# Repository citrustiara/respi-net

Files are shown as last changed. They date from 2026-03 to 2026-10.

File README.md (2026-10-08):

# respi-net

Contactless breathing measurement with a 60 GHz Acconeer A121 radar, and the groundwork for a causal neural network
that recognises breathing phases (inhale, exhale, hold, noise) from the radar alone. Bachelor's thesis project
(praca inżynierska).

The project started with an HB100 Doppler module and IMUs (ESP32 + LSM6DS3). Those were a proof of concept; the
current work is A121-only.

## What is here

- **A121 signal chain** (`src/respi_net/chest_signal.py`): Sparse IQ → presence and chest range gates (Acconeer's
  breathing reference app) → unwrapped phase per gate → echo-weighted average → chest motion in mm (inhale up) →
  driver clock drift correction (0.17 %) → a 2 Hz low-pass as the only filter, so breath holds stay flat.
- **Desktop app** (`respi app`): live A121 view of the signal the network gets (range profile, chest motion and a
  small velocity strip, echo strength in the stats; ~0.2–0.3 s lag), CSV/SQLite recording, and a Recordings tab with curated demo recordings
  (`configs/demo_recordings.json`). Inhale/exhale shading and the older band-pass breathing/heart view are optional,
  under the *View* menu. Also supports HB100, the ESP32 IMU and the iPhone app.
- **iPhone app** (`ios/RespiPhoneIMU/`): streams CoreMotion accelerometer/gyro over BLE, saves every trial on the
  phone as well, remote start/stop from the desktop. Used as a timing helper for labels, never as a network input.
- **Breathing coach** (`respi coach`): the whole session drawn as the breath itself, countdown and next cue; JSON
  patterns in `configs/breathing_patterns/`. Guided recorders log cue times next to the radar and phone data.
- **Breathing-phase data**: classes after Szymański et al. (Sci Data 2025): 0 exhale, 1 hold after exhale,
  2 inhale, 3 hold after inhale, 4 noise, −1 ignored. Per-breath label correction, hand-annotation viewer, a loader
  for the Szymański respiratory-belt dataset (with its 0.2 s label offset corrected), augmented copies and a
  synthetic breathing generator passed through an A121 radar model.
- **Phase models** (`src/respi_net/phase_model.py`): causal TCN (~44k parameters, 25.5 s receptive field) and
  causal GRU (~38k), Viterbi / streaming decoding with phase-transition rules, and a deterministic baseline.
  Nothing has been trained yet; the target recordings are still being collected.
- **Earlier experiments**: lens comparison (hyperbolic, Fresnel zone plate, flat cover; aluminium foil gives no
  gain), sleep nights against a Garmin watch, heart rate from cardiac motion, HB100 vs A121.

## Quick start

```bash
uv sync
uv run respi app --sensor a121                      # live radar (serial port is auto-detected)
uv run respi app --sensor a121 --open data/raw/...csv   # open a recording, no hardware needed
uv run respi coach paced_12_hold                    # breathing coach
uv run respi --help                                 # all commands
uv run pytest -q
```

On macOS the Waveshare A121 board shows up as two ports, `/dev/cu.usbmodem…1` (interface A, the one to use) and
`…3`. Suggested app settings at 0.5–1.5 m: start 0.30 m, end 1.50 m, profile 3, HWAAS 32, 16 sweeps, 20 Hz,
live window 30 s.

Other useful commands:

```bash
uv run respi record-a121-test -p /dev/cu.usbmodemXXXX1 --label my-run    # record A121 until Ctrl+C
uv run respi record-a121-sleep -p /dev/cu.usbmodemXXXX1 --label night-1  # overnight recording + sleep analysis
uv run respi capture-iphone-imu --seconds 60        # iPhone IMU over BLE
uv run python tools/a121_iphone_guided_recording.py # A121 + iPhone with the coach
uv run python tools/annotate_phone_phases.py --session self_lying_3min_01 --run run_01_nn_self_3min --start 40 --length 60
uv run python tools/build_artificial_data.py        # augmented + synthetic training sets
uv run python tools/train_breath_phase_model.py --help
```

Full app and CLI reference: [`docs/APP_AND_CLI.md`](docs/APP_AND_CLI.md).

## Hardware

- Waveshare Acconeer A121 module (60 GHz pulsed coherent radar, USB), with a hyperbolic lens.
- iPhone with the RespiPhoneIMU app (labelling helper).
- Legacy: HB100 10.525 GHz module with a two-stage MCP6002 front end on an ESP32
  ([schematic](hardware/hb100_calibrated_schematic.svg)), LSM6DS3 IMU, AD8232 ECG for future heart-rate labels.

## Layout

- `src/respi_net/` – capture, signal processing, app, coach, datasets, models.
- `tools/` – guided recorders, analyses, dataset builders, training and figure scripts.
- `configs/` – breathing patterns, experiment configs, demo recordings list.
- `annotations/` – reviewed radar labels and small generated example datasets.
- `docs/thesis/` – thesis source (`praca_inzynierska.tex`) and figures; `docs/datasets/` – dataset notes.
- `ios/RespiPhoneIMU/` – iPhone app; `firmware/` – ESP32 firmware for the legacy sensors; `hardware/` – schematics.
- `data/` – recordings (large CSVs and third-party datasets are not committed).

## License

MIT, see [LICENSE](LICENSE). The Szymański et al. dataset is CC BY-NC-ND and is not redistributed here.

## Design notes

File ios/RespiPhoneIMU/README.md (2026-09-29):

# RespiPhoneIMU

Native SwiftUI iPhone companion app for streaming phone IMU data into RespiNet over Bluetooth Low Energy.

## Install on an iPhone

You need a Mac with Xcode for the final build/sign/install step. Apple does not ship the iOS SDK, device installer, or signing toolchain for Windows.

1. Copy or clone this repository on a Mac.
2. Install Xcode from the Mac App Store, then open Xcode once so it finishes installing components.
3. Connect the iPhone with USB, unlock it, and trust the Mac when prompted.
4. Open `ios/RespiPhoneIMU/RespiPhoneIMU.xcodeproj` in Xcode.
5. Select the `RespiPhoneIMU` target, then `Signing & Capabilities`.
6. Choose your Apple ID team. A free Apple ID is usually enough for direct development installs, though the app may expire and need reinstalling.
7. Select your physical iPhone as the run destination.
8. Press Run in Xcode.
9. If iOS asks for Developer Mode, enable it in Settings, restart the phone if prompted, then run again.

The simulator cannot provide real Bluetooth peripheral advertising or useful motion data, so use a physical iPhone. (In the simulator the app draws a made-up breath so its screens can be checked.)

## Using it for recordings

The app is meant to be strapped to the body, screen outwards, while the desktop recorder runs:

- **Before a trial** the main screen shows a checklist (Bluetooth, visible to the Mac, Mac connected, battery
  at least 30%, Low Power Mode off) and a **placement check**: a live line of the chest's tilt over the last
  30 s and its size in mg. With the strap tight, it rises and falls smoothly with each breath.
- **While streaming** a dark full-screen view shows the elapsed time, whether the Mac is connected, the live
  line and the measured rate, readable from a few metres. The screen dims (optional). Nothing on it reacts to
  a quick touch: stopping from the phone takes a 2-second hold, so a strap or shirt cannot stop a trial. The
  recorder normally starts and stops the stream itself.
- **If the Mac drops out** the phone vibrates and shows a red banner; it keeps saving.
- **Every trial is also saved on the phone** as `respi_imu_<date>_<time>.csv` in the same columns as the
  desktop files (`Time_ms,ax,ay,az,gx,gy,gz`, `Time_ms` in Unix ms from the phone's clock). They are listed
  under "Saved on this phone" with share (AirDrop) and delete buttons, and appear in the Files app under
  On My iPhone › Respi IMU. A trial the recorder rejects because Bluetooth lost samples is still complete here.

## Desktop capture

From this repository on the desktop:

```powershell
uv sync
uv run respi iphone-imu-devices
uv run respi capture-iphone-imu --seconds 60
```

Or open the desktop UI:

```powershell
uv run respi app --sensor iphone-imu
```

The saved CSV uses the same schema as the ESP32 IMU path:

```text
Time_ms,ax,ay,az,gx,gy,gz
```

Acceleration is in `g`; gyroscope values are in `deg/s`.

## BLE protocol

- Device name: `RespiPhoneIMU`
- Service UUID: `7B61B4E2-F5B4-4C90-8C7F-A7B2F1E8F4D0`
- Notify characteristic: `7B61B4E3-F5B4-4C90-8C7F-A7B2F1E8F4D0`
- Control characteristic: `7B61B4E4-F5B4-4C90-8C7F-A7B2F1E8F4D0`

The desktop writes ASCII `START` or `STOP` to the control characteristic. Notifications use little-endian binary payloads:

```text
uint8  version = 1
uint8  sample_count
uint16 sequence
repeat sample_count:
  uint32 time_ms_since_stream_start
  int16  ax_mg
  int16  ay_mg
  int16  az_mg
  int16  gx_centi_deg_per_s
  int16  gy_centi_deg_per_s
  int16  gz_centi_deg_per_s
```

The app adapts batch size to the central's `maximumUpdateValueLength`. With a 20-byte BLE payload it sends one sample per notification; with a larger MTU it sends multiple samples per notification.

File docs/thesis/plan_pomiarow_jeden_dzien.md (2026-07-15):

# Plan jednodniowych pomiarów przed spotkaniem z promotorem

Data przygotowania: 15.07.2026

## Cel dnia

W ciągu jednego dnia zebrać mały, ale metodologicznie czytelny zestaw danych,
który pozwoli odpowiedzieć na cztery pytania:

1. Czy sygnał oddechowy z aplikacji iPhone i z LSM6DS3 jest użyteczny w
   podstawowym wariancie leżenia na plecach?
2. Czy HB100 i A121 mogą pracować jednocześnie bez widocznego wzajemnego
   zakłócania?
3. Gdzie w praktyce kończy się użyteczny sygnał oddechowy HB100, gdy A121
   pracuje równolegle jako tor porównawczy?
4. Czy folia daje jakąkolwiek korzyść przy 2 m i czy wynik zależy od tego,
   czy radar pada na klatkę pod naturalnym kątem, czy niemal prostopadle?

Tego dnia nie powstaje szyna ani fantom z silnikiem. Część z siecią neuronową
zostaje do ustalenia z promotorem.

## Zasady wspólne

- Jedna osoba, ta sama odzież, możliwie to samo położenie czujników i stałe
  ustawienie fotela/łóżka w obrębie serii.
- Oddech zadany: metronom 12 odd./min, czyli 0,20 Hz. Wstrzymanie oddechu jest
  kontrolą negatywną, ale nie jest wzorcem amplitudy ani ruchu serca.
- Nagranie podstawowe trwa 60 s. Trzydzieści sekund daje przy 12 odd./min tylko
  sześć cykli, dlatego nadaje się do szybkiej kontroli lub bezdechu, ale jest
  słabe do stabilnej oceny widma.
- Schemat nagrania 60 s: 0–10 s uspokojenie, 10–45 s warunek właściwy,
  45–60 s wstrzymanie oddechu. Jeżeli wstrzymanie 15 s jest niekomfortowe,
  skrócić je; nie forsować go.
- Warunki A/B wykonywać parami i odwracać kolejność, np. AB, BA, AB. Nie robić
  całego bloku A, a potem całego bloku B.
- Nie używać `resp_confidence` ani `signal_quality` jako głównych wyników,
  ponieważ w dotychczasowych danych nasycały się. Zapisywać SNR widmowy,
  prominencję piku, trafienie zadanej częstości i stabilność między oknami.
- Przed startem utworzyć dziennik sesji. Minimalne kolumny:
  `run_id, czas, urządzenia, pozycja, dystans, folia, konfiguracja, kolejność,
  pliki, uwagi`.
- Po każdej serii od razu wpisać nazwy powstałych plików. Pliki HB100 nie mają
  etykiety warunku w nazwie, więc bez dziennika szybko tracą znaczenie.
- Dystans ustawiać tym samym dalmierzem MILESEEY D2 40 m. Radar pozostawić na
  statywie Manfrotto, a plamką lasera sprawdzać orientacyjne skierowanie osi na
  środek klatki piersiowej. W dzienniku zapisywać także wysokość i kąt albo
  przesunięcie poprzeczne stanowiska.

## Warunek konieczny: czas LSM6DS3

Obecny firmware LSM6DS3 wysyła sześć wartości bez czasu próbki, a komputer
nadaje czas przy odbiorze linii UART. Buforowanie może tworzyć zduplikowane lub
silnie skupione timestampy. Przed analizą ilościową trzeba:

1. dodać w firmware czas z `esp_timer_get_time()` albo monotonny licznik
   próbki,
2. przesyłać go jako pierwsze pole wiersza,
3. odczytać go w `src/respi_net/imu.py`, zamiast nadawać każdej linii
   `time.time()` na hoście,
4. w 60-sekundowym nagraniu nieruchomego czujnika sprawdzić medianę, histogram
   i percentyle odstępów czasu oraz liczbę odstępów równych zero.

Jeśli poprawka nie działa do 09:30, nie blokować całego dnia. Wykonać pełny
test iPhone, a LSM6DS3 potraktować wyłącznie jakościowo i jawnie opisać
ograniczenie czasowe.

## Harmonogram

| Czas | Zadanie | Wynik |
|---|---|---|
| 08:30–09:30 | timestamp LSM6DS3, test 60 s obu urządzeń nieruchomo | poprawna oś czasu lub jawny fallback |
| 09:30–10:15 | iPhone + LSM6DS3: leżenie na plecach | 4 wspólne nagrania po 60 s |
| 10:45–11:30 | test zakłóceń HB100–A121 | decyzja: razem czy osobno |
| 11:30–13:00 | przerwa i przygotowanie stanowiska dystansowego | geometria i lista dystansów |
| 13:00–14:30 | zasięg HB100; równolegle A121, jeśli test zakłóceń przeszedł | krzywa trafień/SNR względem dystansu |
| 14:30–15:45 | retest folii przy 2 m: geometria naturalna i prostopadła, tylko soczewka hiperboliczna | układ 2×2: kąt × folia |
| 15:45–16:30 | opcjonalny test odchylenia od osi A121, jeżeli wcześniejsze bloki skończą się poprawnie | sprawdzenie hipotezy o szerokości pola widzenia |
| 16:30–18:00 | kontrola plików, analiza, wykresy, kopia danych | materiał do pracy i dla promotora |

## 1. Test iPhone oraz LSM6DS3

Umieścić telefon i LSM6DS3 obok siebie na górnej części tułowia. Nie są w tym
eksperymencie referencją dla radaru; porównywane są dwa warianty samodzielnej
metody inercyjnej. Pozycja nie będzie identyczna co do milimetra, więc
porównanie amplitud między urządzeniami ma znaczenie drugorzędne.

Macierz minimalna:

| ID | Pozycja | Oddech | Powtórzenia | Czas |
|---|---|---:|---:|---:|
| IMU-L-N | na plecach | swobodny + końcowe wstrzymanie | 2 | 60 s |
| IMU-L-12 | na plecach | 12/min + końcowe wstrzymanie | 2 | 60 s |

Łącznie: 4 minuty czystego nagrania. Telefon i moduł położyć obok siebie na
górnej części klatki piersiowej i nie zmieniać ich orientacji między
powtórzeniami. Tego dnia nie rozszerzać macierzy o siedzenie, bok, brzuch,
stanie ani wiele lokalizacji. Wynik ma odpowiedzieć wyłącznie na pytanie, czy
oba tory dają użyteczny sygnał w najprostszym wariancie na plecach.

**TODO po teście podstawowym:** jeżeli oba urządzenia spełnią kryterium
użyteczności, wykonać osobną serię w pozycji siedzącej, a dopiero później
sprawdzić bok, różne ułożenia telefonu i odporność PCA na orientację. Bez tych
danych nie formułować wniosku o niezależności metody od postawy.

Komendy uruchamiane w dwóch terminalach:

```bash
uv run respi capture-imu --port <PORT_LSM6> --no-plot
uv run respi capture-iphone-imu --seconds 60 --no-plot
```

LSM6DS3 kończy się `Ctrl+C`; warto uruchomić go kilka sekund przed iPhone'em i
zatrzymać kilka sekund po nim.

Raportować osobno dla przyspieszenia i żyroskopu/PCA:

- rzeczywistą częstość próbkowania i histogram `Δt`,
- liczbę braków/powtórzeń czasu; dla BLE także luki sekwencji paczek (obecny
  odbiornik zachowuje ostatni numer, ale nie zlicza jeszcze przeskoków),
- częstotliwość dominującą i błąd względem 0,20 Hz w próbach z metronomem,
- SNR piku oddechowego i jego spadek podczas wstrzymania oddechu,
- stabilność wyniku między powtórzeniami w pozycji na plecach,
- udział wariancji wyjaśniony przez pierwszą składową PCA.

Robocze kryterium użyteczności: pik przy 0,20 Hz z błędem nie większym niż
0,02 Hz, co najmniej 6 dB nad medianą tła w paśmie oraz wyraźny spadek mocy
oddechowej podczas wstrzymania. Progi są kryteriami tego eksperymentu, a nie
normą kliniczną.

## 2. Czy HB100 i A121 mogą nagrywać równocześnie?

Ich częstotliwości podstawowe są daleko od siebie: HB100 pracuje przy
10,525 GHz, a A121 w paśmie 57–64 GHz. Bezpośrednie zakłócenie na
częstotliwości podstawowej jest więc mało prawdopodobne. Nie wolno jednak
przyjąć z góry, że zakłóceń nie ma: szósta harmoniczna HB100 wypada przy około
63,15 GHz, czyli wewnątrz pasma A121, a zakłócenie może też wejść przez wspólne
zasilanie USB lub przewody.

Ustawić oba radary tak jak w wykonanym pomiarze docelowym: obok siebie,
z~jednakowym nachyleniem, środkami apertur oddalonymi o 15 cm i~taką samą
odległością obu radarów od tułowia. Wykonać jeden krótki zapis każdego warunku:

| Warunek | A121 | HB100 | Scena |
|---|---|---|---|
| INT-A | nagrywa | wyłączony z zasilania | pusty, nieruchomy pokój |
| INT-B | nagrywa | włączony i nagrywa | pusty, nieruchomy pokój |
| INT-C | wyłączony z zasilania | nagrywa | pusty, nieruchomy pokój |

Każde nagranie: 30 s. Dla A121 porównać amplitudę tła i widmo szumu fazowego w
tej samej bramce; dla HB100 — RMS i widmo napięcia w pasmach 0,1–0,6 Hz oraz
0,6–5 Hz. Zmiana większa niż 3 dB, nowa stała linia widmowa albo wyraźna utrata
ramek jest sygnałem ostrzegawczym. Wtedy powtórzyć jedną parę z osobnymi
zasilaniami/hubami. Jeśli problem pozostaje, nie nagrywać radarów równocześnie.

Przykładowe terminale dla warunku wspólnego:

```bash
uv run respi capture-radar --port <PORT_HB100> --no-plot
uv run respi record-a121-test --port <PORT_A121> --seconds 30 \
  --label int-b-both --start-m 0.2 --end-m 1.5 \
  --profile 3 --hwaas 32 --sweeps-per-frame 8 --frame-rate-hz 20
```

## 3. Praktyczny limit HB100 z równoległym zapisem A121

### Wariant minimalny do wykonania teraz

Jeżeli celem jest przed spotkaniem pokazać przede wszystkim, **co da się
wycisnąć z HB100**, nie trzeba od razu wykonywać pełnej serii do 4 m. Najkrótszy
zestaw, który zachowuje sens metodyczny, wygląda następująco:

1. Zamocować HB100 i A121 obok siebie, z odległością środków apertur 15 cm,
   na wysokości mostka i z jednakowym nachyleniem. Dalmierzem ustawić tę samą
   odległość obu radarów od tułowia. A121 pozostawić z płaską pokrywą: jej
   szerokie pole widzenia jest bardziej porównywalne z HB100 niż pole soczewek
   skupiających, a sama osłona nie jest tu przedmiotem badania.
2. W pustej, nieruchomej scenie wykonać po 30 s: A121 przy wyłączonym HB100,
   oba radary włączone oraz HB100 przy wyłączonym A121. Jest to tylko szybki
   test przesiewowy zakłóceń. Gdy pojawi się nowa linia widmowa, wzrost tła
   ponad 3 dB albo utrata ramek, podejrzaną parę powtórzyć z osobnymi portami
   USB/zasilaniem; przy braku różnicy przejść od razu do pomiarów wspólnych.
3. Wykonać wspólne nagrania przy 30 cm (dwa powtórzenia), 60 cm (dwa
   powtórzenia) i 100 cm (dwa powtórzenia). Nie zmieniać wzmocnienia toru HB100
   między dystansami i zapisać, czy ADC nie ulega nasyceniu.
4. Jeżeli 100 cm spełnia kryterium użyteczności, wykonać jedno nagranie przy
   150 cm. Po sukcesie zwiększać dystans co 50 cm aż do pierwszego
   niepowodzenia. Powtórzyć tylko najdalszy dystans zaliczony oraz pierwszy
   niezaliczony. W powtórzeniu nieudanego warunku ponownie usiąść albo
   przesunąć krzesło radialnie o 1–2 cm, ponieważ jedokanałowy HB100 może
   znaleźć się w punkcie małej czułości fazowej. Dopiero niepowodzenie obu
   ustawień uznać za granicę; to wystarcza do podania jej praktycznego
   przedziału bez rozbudowanej macierzy.

Każde nagranie powinno trwać 90 s i powtarzać już użyty protokół A121:
10 s oddechu swobodnego, 7 cykli po 5 s (wdech 2 s, wydech 3 s), 15 s
wstrzymania po wydechu oraz 6 kolejnych cykli. Nie wykonywać na początku
dodatkowych ruchów synchronizacyjnych: prowadzony skrypt zapisuje dla obu
torów wspólny czas hosta, a pierwsze 10 s służy ustabilizowaniu pozycji.
Warunek zalicza się dla HB100, gdy pik przy 0,20 ± 0,02 Hz jest obecny w obu
częściach oddychania, ma co najmniej 6 dB nad tłem i wyraźnie zanika podczas
wstrzymania. A121 służy do sprawdzenia, czy w tym samym czasie rzeczywiście
zarejestrowano zadany przebieg; nie jest wzorcem klinicznym.

Taki wariant zajmuje około 10–15 minut czystego nagrywania plus zmiany
dystansu. Daje najlepszy przypadek, dwa powtórzenia przy odległościach
praktycznych oraz przedział granicy zasięgu. Dodatkowe dystanse i pełne
odwrócenie kolejności mają sens dopiero wtedy, gdy ta seria działa i ma zostać
użyta do mocniejszego wniosku ilościowego.

Prowadzony zapis całej procedury uruchamia osobny program:

```bash
uv run python tools/hb100_a121_guided_experiment.py
```

Program zapisuje HB100 i~A121 do osobnych plików CSV, dodaje wspólny czas hosta
i~plik z~fazami oddechu, prowadzi wszystkie trzy próby pustej sceny oraz dwie
próby przy 30, 60 i~100 cm. Klawisz `Esc` przerywa i~usuwa bieżący zapis. Po
100 cm można z~interfejsu dodać 150 cm i~kolejne dystanse co 50 cm; pierwsza
oznaczona porażka jest automatycznie powtarzana po zmianie pozycji o~1–2 cm.
Gdy podłączony jest tylko tor HB100, jego transmisję można najpierw sprawdzić
bez tworzenia właściwej sesji. Aktualny firmware używa 230400 baud i~stabilnej
częstości 250 Hz; skrypt sprawdza tę szybkość transmisji jako pierwszą, a tryb
zgodności pozostawia wyłącznie dla starszego obrazu 921600 baud:

```bash
uv run python tools/hb100_a121_guided_experiment.py --probe-hb100
```

### Wariant rozszerzony z pełną krzywą dystansu

Po pozytywnym teście zakłóceń nagrywać oba radary równocześnie. W tym
rozszerzonym wariancie A121 ma tylko soczewkę hiperboliczną; soczewki
zaprojektowanej dla około 60 GHz nie należy
zakładać na HB100 pracujący przy 10,525 GHz. Radary ustawić na wysokości
mostka, równolegle, bez zmiany statywów w całej serii.

Kolejność pierwszej serii, celowo niemonotoniczna:

`0,5 m → 2,0 m → 1,0 m → 3,0 m → 1,5 m → 4,0 m → 2,5 m`

Jeżeli pomieszczenie nie pozwala na 4 m, zakończyć na najdalszym mierzalnym
dystansie i podać ograniczenie pomieszczenia. Zrobić dwa powtórzenia każdego
dystansu, drugie w odwrotnej kolejności. Pomiędzy powtórzeniami wstać i usiąść
ponownie — pokaże to praktyczną wrażliwość HB100 na małą zmianę średniej
odległości bez budowania precyzyjnej szyny.

Stałe ustawienia A121: profil 3, HWAAS 32, 8 sweepów/ramkę, 20 Hz. Okno
odległościowe można przesuwać wraz z celem, ale powinno mieć stałą szerokość
około 1 m. Przykład dla 2 m:

```bash
uv run respi record-a121-test --port <PORT_A121> --seconds 60 \
  --label range-2m-r1 --start-m 1.5 --end-m 2.5 \
  --profile 3 --hwaas 32 --sweeps-per-frame 8 --frame-rate-hz 20
```

W drugim terminalu podczas tego samego warunku:

```bash
uv run respi capture-radar --port <PORT_HB100> --no-plot
```

Na początku i końcu wspólnego pomiaru wykonać trzy krótkie, wyraźne ruchy
tułowiem. Znaczniki HB100 są czasem od uruchomienia ESP32, a A121 używa czasu
hosta, więc te ruchy pozwalają później wyrównać przebiegi. Do porównania samej
częstości oddechu dokładna synchronizacja nie jest konieczna.

Za trafienie uznać pik `0,20 ± 0,02 Hz`, obecny w kolejnych oknach i z SNR co
najmniej 6 dB. Dla HB100 dodatkowo policzyć stosunek energii 0,20 Hz do drugiej
harmonicznej 0,40 Hz. Dominacja 0,40 Hz jest praktycznym przykładem ograniczenia
jednokanałowego CW, a nie poprawną detekcją 24 odd./min.

Zasięg roboczy raportować jako najdalszy dystans spełniający kryterium w obu
powtórzeniach. Najbliższy dystans niespełniający kryterium powtórzyć trzy razy
po 60 s. Jeśli A121 zawiedzie, wykonać tylko jedną serię ratunkową z profilem 4
i HWAAS 128; oznaczyć ją jako konfigurację strojoną i nie mieszać z serią
podstawową.

## 4. Retest folii przy 2 m: geometria naturalna i prostopadła

**Status: wykonano 15 lipca 2026.** Zarejestrowano komplet 12 prób w sesji
`guided_foil2m_2026-07-15_16-26-15`. Analizę odtwarza
`tools/analyze_a121_foil_2m.py`; wyniki i wnioski wpisano do sekcji
„Retest folii i kąta padania na dystansie 2 m” pracy.

Celem retestu jest rozdzielenie dwóch możliwych wyjaśnień dotychczasowego
wyniku: folia rzeczywiście nie poprawia pomiaru albo przy naturalnym kącie
odbicie zwierciadlane jest kierowane poza radar.

Ustawienia wspólne:

- wyłącznie A121 z soczewką hiperboliczną;
- dystans 2,0 m, profil 3, HWAAS 32, 8 sweepów/ramkę, 20 Hz, zakres 1,5–2,5 m;
- pozycja siedząca na tym samym krześle i ta sama warstwa odzieży;
- łata 5 × 5 cm; jej górna krawędź 5 cm poniżej poziomej linii łączącej
  brodawki sutkowe;
- każde nagranie 90 s według identycznych komunikatów programu:
  0–10 s oddech swobodny, 10–45 s siedem cykli 12/min (wdech 2 s, wydech
  3 s), 45–60 s wstrzymanie po wydechu i 60–90 s sześć kolejnych cykli
  12/min. Wstrzymania nie forsować; przy dyskomforcie przerwać i odrzucić
  próbę.

Badane są dwa ustawienia geometryczne:

- **N — naturalne:** niewymuszona pozycja siedząca, radar równoległy do
  podłoża i sprawdzony poziomnicą pęcherzykową. Oś radaru tworzy około 30° z
  normalną do klatki, tak jak w pierwszym eksperymencie.
- **P — prawie prostopadłe:** wiązka pada możliwie pod kątem 90° do
  powierzchni klatki, czyli 0° względem jej normalnej. Najlepiej uzyskać to
  przez zmianę pochylenia i wysokości głowicy statywu, bez wymuszania innej
  pozycji ciała. Oś nadal ma trafiać w środek łaty, a odległość pozostać 2,0 m.

Dla każdego ustawienia wykonywane są nagrania z folią i bez folii:

| Kod | Geometria | Folia |
|---|---|---|
| N0 | naturalna, około 30° od normalnej | brak |
| NF | naturalna, około 30° od normalnej | jest |
| P0 | prawie 90° do powierzchni / 0° od normalnej | brak |
| PF | prawie 90° do powierzchni / 0° od normalnej | jest |

### Weryfikacja ustawienia prostopadłego laserem

1. Dalmierz ustawić sztywno przy radarze tak, aby jego oś lasera była
   równoległa do osi A121; sposób mocowania sfotografować.
2. Z założoną i możliwie wygładzoną folią skierować laser w środek łaty.
3. Regulować pochylenie głowicy statywu do chwili, gdy odbity punkt lasera
   wraca możliwie blisko miejsca emisji. Powrót obserwować na małej matowej,
   białej kartce umieszczonej przy aperturze dalmierza, a nie patrząc wzdłuż
   wiązki ani w jej zwierciadlane odbicie.
4. Zablokować głowicę i zaznaczyć pozycję krzesła. Ustawienie opisać jako
   „prawie prostopadłe”, ponieważ pofałdowana folia i krzywizna klatki nie
   tworzą idealnej płaszczyzny.
5. Zaznaczyć dwa powtarzalne położenia głowicy statywu: N (naturalne) i P
   (prawie prostopadłe). W bloku z folią przełączać wyłącznie położenie
   statywu, nie odklejając łaty.
6. Po szóstej próbie, zakończonej w warunku PF, zdjąć folię jeden raz bez
   zmiany statywu ani krzesła i od razu wykonać P0. W całym drugim bloku
   odtwarzać N i P z oznaczeń, bez ponownego przyklejania folii.

Każdy z czterech warunków wykonać trzy razy. Folia jest przyklejana tylko raz
przed próbą 1 i zdejmowana tylko raz między próbą 6 a 7. Kolejność geometrii
jest odwrócona w drugim bloku:

- blok z folią: `NF → PF → PF → NF → NF → PF`,
- blok bez folii: `P0 → N0 → N0 → P0 → P0 → N0`.

Taki układ eliminuje odklejanie i ponowne przyklejanie łaty, ale nie rozdziela
w pełni efektu folii od dryfu w czasie: wszystkie pomiary z folią są wykonane
wcześniej. Wynik należy więc opisać jako pilotażowy, a spójny spadek lub wzrost
wszystkich metryk w drugim bloku traktować również jako możliwy efekt sesji.

Daje to 12 nagrań i po trzy realizacje każdego warunku. Przykładowa komenda:

```bash
uv run python tools/a121_foil_2m_experiment.py
```

Runner sam realizuje powyższą kolejność i wyraźnie wskazuje moment jednorazowego
zdjęcia folii. Pokazuje duże komunikaty `WDECH`,
`WYDECH` i `WSTRZYMAJ ODDECH`, odlicza czas do zmiany oraz zapisuje rozwiniętą
oś poleceń w manifeście sesji. `Esc` lub czerwony przycisk przerywa aktywną
próbę i usuwa jej plik; ten sam warunek pozostaje wtedy gotowy do ponowienia.

Najpierw policzyć efekt folii osobno dla obu geometrii:

- `ΔN = NF − N0` — efekt folii w pozycji naturalnej,
- `ΔP = PF − P0` — efekt folii przy padaniu prawie prostopadłym,
- `ΔP − ΔN` — informacja, czy korzyść z folii zależy od kąta.

Porównać amplitudę w bramce klatki, SNR, prominencję piku, stabilność
odległości i trafienie 0,20 ± 0,02 Hz. Jeśli poprawa pojawi się tylko w PF,
wynik będzie wspierał hipotezę o kierowaniu odbicia poza radar w naturalnej
geometrii. Brak poprawy w NF i PF będzie wskazywał, że łata nie daje praktycznej
korzyści również przy korzystnym ustawieniu. Przy trzech powtórzeniach wynik
pozostaje pilotażowy: pokazać wszystkie punkty i mediany różnic, bez mocnego
wniosku opartego wyłącznie na p-value.

## 5. Opcjonalny test odchylenia od osi A121

Ten test ma większą wartość dla głównego, radarowego tematu pracy niż dalsze
rozszerzanie macierzy IMU. Sprawdza hipotezę, że soczewka skupiająca daje
większy zysk przy poprawnym wycelowaniu, ale płaska pokrywa jest bardziej
odporna na przesunięcie śpiącej osoby poza oś radaru.

- Dystans nominalny: 1,0 m. Przy tym dystansie dotychczasowy SNR jest duży,
  więc spadku jakości nie powinien powodować sam brak mocy.
- Warianty: soczewka hiperboliczna i płaska pokrywa; FZP pominąć.
- Położenie środka klatki poza osią głównej wiązki: 0°, 15° i 30°.
- Dwa powtórzenia każdego warunku, po 60 s, oddech 12/min.
- Kolejność przeplatać między soczewkami i kątami.
- Metryki: amplituda w bramce klatki, SNR, prominencja piku, stabilność
  śledzonej odległości i odsetek okien trafiających 0,20 ± 0,02 Hz.

Jeżeli statyw nie ma wiarygodnej podziałki kąta, można pozostawić radar
nieruchomo i przesunąć badanego poprzecznie względem osi. Dla odległości 1 m
przesunięcia odpowiadające w przybliżeniu 15° i 30° wynoszą odpowiednio
0,27 m i 0,58 m (`x = R·tan(θ)`). Bez wykonania tego testu w pracy należy
pozostawić sformułowanie „prawdopodobne wyjaśnienie geometryczne”, a nie
„przyczyną była niewłaściwa pozycja radaru”.

Nie należy mylić tego testu z kątem padania na powierzchnię klatki. Retest
z sekcji 4 porównuje 30° i 0° względem normalnej, aby zbadać kierunkowość
odbicia od folii. Test odchylenia od osi pozostawia orientację tułowia stałą,
ale przesuwa jego środek poza główną oś radaru, aby zbadać pole widzenia
soczewek.

## Wykresy do zrobienia tego samego dnia

1. iPhone i LSM6DS3: sygnał + PSD dla leżenia na plecach oraz histogram `Δt`.
2. Trafienie 0,20 Hz i SNR względem dystansu dla A121 i HB100.
3. HB100: energia składowej podstawowej 0,20 Hz oraz harmonicznej 0,40 Hz w
   każdym powtórzeniu.
4. Folia 2 m: delty `NF−N0` i `PF−P0` dla amplitudy i SNR oraz porównanie
   efektu folii między geometrią naturalną i prostopadłą.
5. Jeżeli wykonano test kąta: SNR i odsetek trafionych okien względem kąta,
   osobne krzywe dla soczewki hiperbolicznej i płaskiej pokrywy.

## Minimalny rezultat dla promotora

Nawet gdy część prób zawiedzie, dzień jest udany, jeżeli powstaną:

- jawny wniosek o jakości timestampów i BLE,
- tabela „iPhone/LSM6DS3 × oddech swobodny/narzucony” dla pozycji na plecach,
  z kryteriami użyteczności,
- test wykluczający albo ujawniający zakłócenia HB100–A121,
- empiryczna granica odległości z warunkiem trafienia, a nie oceną „na oko”,
- uczciwy pilotaż folii przy 2 m wykonany w dwóch kolejnych blokach (najpierw
  wszystkie próby z folią, następnie wszystkie bez niej), osobno dla
  naturalnego kąta i padania prawie prostopadłego.

Test kąta jest dodatkiem o dużej wartości interpretacyjnej, ale nie jest
warunkiem minimalnego wyniku dnia.

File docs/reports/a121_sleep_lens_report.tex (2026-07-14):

\documentclass[11pt,a4paper]{article}
\usepackage[utf8]{inputenc}
\usepackage[T1]{fontenc}
\usepackage[margin=2.4cm]{geometry}
\usepackage{graphicx}
\usepackage{booktabs}
\usepackage{array}
\usepackage{longtable}
\usepackage{float}
\usepackage{subcaption}
\usepackage{hyperref}
\usepackage{amsmath}
\usepackage{caption}
\usepackage{siunitx}
\graphicspath{{../../data/plots/}}

\title{A121 Sleep Radar Lens Experiments\\\large Overnight comparison of plano-convex, FZP, and flat-cover configurations with Garmin reference data}
\author{}
\date{June 2026}

\begin{document}
\maketitle

\begin{abstract}
This report summarizes three overnight A121 radar sleep recordings and two short follow-up bench tests performed while changing the front-end optical/mechanical configuration: a plano-convex lens (night 1\_1), a Fresnel zone plate (FZP) lens (night 2), and a flat cover that behaved approximately like a no-lens condition (night 3). Garmin heart-rate (HR), respiration-rate (RR), and sleep-stage overlays were used as the main external reference. A key result of the analysis is that raw radar \texttt{peak\_amplitude} cannot be interpreted as chest-signal strength in this setup, because the radar was placed near the bed edge and the dominant reflector was often closer than the tracked subject distance. The most meaningful comparison therefore comes from Garmin agreement and from the plausibility/stability of the radar-derived sleep metrics. Night 3, despite having no focusing lens, produced the closest HR agreement to Garmin, while nights 1\_1 and 2 showed larger HR bias and heuristic REM$\rightarrow$deep transitions not present in Garmin. The short \SI{2}{m} retest showed only a small amplitude increase with the plano-convex lens compared with no lens, but the lens produced more plausible HR estimates.
\end{abstract}

\section{Background and framing}
Acconeer's lens design documentation notes that dielectric lenses are mainly used to shape the radiation pattern, increase gain, narrow the beamwidth, and in some cases suppress unwanted reflections. The same documentation presents both a plano-convex example lens and an FZP example lens for A121-class hardware, and explicitly notes that focal distance may require tuning because the optimum can shift due to the radome, housing, material tolerances, and nearby mechanics. This point is directly relevant here because the experiments were performed in a bedroom geometry with the radar mounted near the bed edge rather than in a controlled free-space test fixture.

\paragraph{Interpretation rule used throughout this report.}
\begin{quote}
\textbf{Raw \texttt{peak\_amplitude} is treated only as a dominant-return engineering metric, not as a direct proxy for chest reflection strength or physiological signal quality.} The reason is that the strongest radar return could originate from the bed edge, mattress, bedding, or another static reflector rather than the subject.
\end{quote}

This framing is important because the raw peak amplitudes differed by more than an order of magnitude between nights, yet the strongest returns were often not spatially aligned with the tracked target distance.

\section{Experimental conditions}
Table~\ref{tab:nights} summarizes the three overnight recordings used in the comparison. Night 3 was interrupted, so it contains only about three hours of usable data. The Garmin overlay plots and the radar sleep-score JSON sidecars were generated for all three nights.

\begin{table}[H]
\centering
\caption{Overnight recordings and hardware condition.}
\label{tab:nights}
\begin{tabular}{@{}lllll@{}}
\toprule
Night & Date & Front-end condition & Recording length & Note \\
\midrule
1\_1 & 2026-06-08 & Plano-convex lens & 6.95 h & Full night \\
2 & 2026-06-09 & FZP lens & 6.48 h & Full night \\
3 & 2026-06-10 & Flat cover / effectively no lens & 3.56 h & Interrupted recording \\
\bottomrule
\end{tabular}
\end{table}

The A121 lens documentation is useful for interpreting these tests:
\begin{itemize}
    \item dielectric lenses can increase gain and narrow the beam,
    \item the plano-convex and FZP lenses are both valid A121-compatible example designs,
    \item FZP lenses are mechanically thinner and their thickness is less coupled to diameter,
    \item the effective focal point can shift because of radome/housing effects and nearby mechanics.
\end{itemize}
These points make aiming and lens-to-radar spacing critical, especially in a bed-edge mounting geometry.

\section{Analysis method}
The overnight data were processed with the repository's A121 sleep-analysis pipeline. For each night the following outputs were generated and used here:
\begin{itemize}
    \item gated radar HR/RR trends,
    \item radar sleep-phase heuristic and radar sleep score,
    \item Garmin HR/RR overlays,
    \item radar sleep-parameter JSON sidecars,
    \item diagnostic comparison plots.
\end{itemize}

The following metrics were extracted:
\begin{enumerate}
    \item radar sleep score, total sleep time, efficiency, and estimated resting HR,
    \item mean and median HR/RR compared against Garmin,
    \item sleep-stage duration sums (where available from the analysis session),
    \item direct REM$\rightarrow$deep transition counts,
    \item dominant-return peak amplitude and its spatial alignment to the tracked target distance,
    \item short timed lens vs. no-lens retest diagnostics at roughly \SI{2}{m}.
\end{enumerate}

Estimated resting HR was added to the automatic radar sleep JSON files and defined as the \emph{10th percentile of quiet, non-awake radar HR windows inside the inferred sleep interval}. This makes it more robust than taking a raw minimum while still approximating the lower resting envelope overnight.

\section{Primary overnight results}

\subsection{Radar-only sleep summary}
Table~\ref{tab:radarsleep} summarizes the radar-inferred overnight sleep metrics.

\begin{table}[H]
\centering
\caption{Radar sleep summary from the generated JSON sidecars.}
\label{tab:radarsleep}
\resizebox{\textwidth}{!}{%
\begin{tabular}{@{}lrrrrr@{}}
\toprule
Night & Score & Total sleep [min] & Efficiency [\%] & Estimated resting HR [bpm] & Quality \\
\midrule
1\_1 & 74 & 364.5 & 93.8 & 52.7 & Fair \\
2 & 71 & 342.5 & 95.0 & 51.9 & Fair \\
3 & 49 & 154.0 & 85.8 & 50.8 & Poor \\
\bottomrule
\end{tabular}%
}
\end{table}

Night 3 scored substantially worse mainly because the recording was interrupted and therefore short; the score was capped by duration. The estimated resting HR remained internally consistent across nights, staying in the low-50 bpm range.

\subsection{Heart-rate comparison against Garmin}
Garmin agreement is the most important outcome because it is much less sensitive to the bed-edge reflector issue than raw radar amplitude. Table~\ref{tab:hr} uses the sleep-only comparison windows discussed during the analysis session.

\begin{table}[H]
\centering
\caption{Sleep-only heart-rate comparison between radar and Garmin.}
\label{tab:hr}
\resizebox{\textwidth}{!}{%
\begin{tabular}{@{}lrrrrrr@{}}
\toprule
Night & Radar mean & Radar median & Garmin mean & Garmin median & Mean bias & Median bias \\
 & [bpm] & [bpm] & [bpm] & [bpm] & radar$-$Garmin & radar$-$Garmin \\
\midrule
1\_1 & 55.5 & 55.2 & 57.4 & 57.0 & -1.9 & -1.8 \\
2 & 55.1 & 54.6 & 58.3 & 57.0 & -3.3 & -2.4 \\
3 & 53.8 & 53.3 & 53.6 & 52.0 & +0.1 & +1.3 \\
\bottomrule
\end{tabular}%
}
\end{table}

The HR comparison shows the clearest practical result of the experiment: the flat-cover night (night 3) matched Garmin best, while the two lensed nights under-read HR on average. This does \emph{not} prove that the flat cover is universally better than a lens; it does show that the tested lens geometries did not automatically translate into better overnight physiological agreement in this mounting arrangement.

\subsection{Respiration-rate comparison against Garmin}
RR agreement was generally closer than HR agreement. Table~\ref{tab:rr} summarizes the values used during the analysis.

\begin{table}[H]
\centering
\caption{Sleep-only respiration-rate comparison between radar and Garmin.}
\label{tab:rr}
\resizebox{\textwidth}{!}{%
\begin{tabular}{@{}lrrrrrr@{}}
\toprule
Night & Radar mean & Radar median & Garmin mean & Garmin median & Mean bias & Median bias \\
 & [brpm] & [brpm] & [brpm] & [brpm] & radar$-$Garmin & radar$-$Garmin \\
\midrule
1\_1 & 13.6 & 14.2 & 14.0 & 14.4 & -0.4 & -0.2 \\
2 & 14.6 & 14.9 & 14.2 & 14.4 & +0.4 & +0.5 \\
3 & 14.3 & 14.3 & 14.0 & 14.1 & +0.3 & +0.2 \\
\bottomrule
\end{tabular}%
}
\end{table}

RR stayed within about half a breath per minute of Garmin on average for all three nights. This is a stronger and more stable result than the raw peak-amplitude comparison.

\subsection{Sleep-stage duration comparison}
For nights 1\_1 and 2, the analysis session retained quantitative radar-vs-Garmin sleep-stage duration sums extracted from the Garmin FIT stage data. These values are shown in Table~\ref{tab:stages}. Night 3 was interrupted and is therefore discussed primarily through the overlay plot and radar-only sleep summary.

\begin{table}[H]
\centering
\caption{Sleep-stage duration sums for nights 1\_1 and 2. Positive difference means radar assigned more time to that stage than Garmin.}
\label{tab:stages}
\resizebox{\textwidth}{!}{%
\begin{tabular}{@{}llrrrr@{}}
\toprule
Night & Source & Awake [min] & Light [min] & Deep [min] & REM [min] \\
\midrule
1\_1 & Radar & 24.0 & 212.5 & 78.5 & 73.5 \\
1\_1 & Garmin & 40.0 & 222.0 & 57.0 & 47.0 \\
1\_1 & Difference & -16.0 & -9.5 & +21.5 & +26.5 \\
\midrule
2 & Radar & 18.0 & 191.0 & 58.0 & 93.5 \\
2 & Garmin & 5.0 & 211.0 & 18.0 & 117.0 \\
2 & Difference & +13.0 & -20.0 & +40.0 & -23.5 \\
\bottomrule
\end{tabular}%
}
\end{table}

Two additional stage-related observations were important:
\begin{itemize}
    \item Nights 1\_1 and 2 contained direct radar REM$\rightarrow$deep transitions (two such transitions on each night), while Garmin showed zero direct REM$\rightarrow$deep transitions in those same nights.
    \item This suggests that at least part of the radar stage disagreement came from the heuristic classifier rather than from the raw HR/RR tracking alone.
\end{itemize}

\section{Why peak amplitude must be interpreted carefully}
The raw peak-amplitude plot across nights is striking: the median dominant return rises from roughly \num{1.7e3} in night 1\_1 to \num{1.75e4} in night 2 and \num{2.36e4} in night 3. However, Table~\ref{tab:peak} shows why this cannot be interpreted as ``better chest signal''.

\begin{table}[H]
\centering
\caption{Dominant-return amplitude and target-alignment diagnostics from the gated sleep-vitals CSV files.}
\label{tab:peak}
\resizebox{\textwidth}{!}{%
\begin{tabular}{@{}lrrrrrr@{}}
\toprule
Night & Peak amp median & Peak amp mean & Median target dist & Median peak dist & Median $|\Delta d|$ & Fraction with $|\Delta d|\leq$0.10 m \\
 & [a.u.] & [a.u.] & [m] & [m] & [m] & [-] \\
\midrule
1\_1 & 1665.2 & 3079.7 & 0.37 & 0.15 & 0.16 & 0.316 \\
2 & 17515.5 & 17659.7 & 0.44 & 0.12 & 0.32 & 0.012 \\
3 & 23574.3 & 23240.3 & 0.22 & 0.10 & 0.12 & 0.384 \\
\bottomrule
\end{tabular}%
}
\end{table}

The median dominant-return distance was much closer than the tracked target distance on all nights, especially on night 2. The FZP night is the clearest example: despite a median peak amplitude above \num{1.7e4}, only about \SI{1.2}{\percent} of windows had the dominant peak within \SI{10}{cm} of the target. This makes it highly likely that the large peak came from the bed edge or another nearby reflector rather than from the subject.

This is the reason for the specific presentation used in this report:
\begin{enumerate}
    \item Garmin HR/RR agreement is treated as the \textbf{primary outcome},
    \item sleep-stage agreement is treated as the \textbf{secondary outcome},
    \item raw peak amplitude is treated only as a \textbf{contextual engineering variable}. 
\end{enumerate}

\section{Short follow-up retest at approximately \SI{2}{m}}
A short retest was performed after the overnight analysis to check whether the plano-convex lens behaved more sensibly at a longer distance, where aiming is easier. One \SI{90}{s} sample was recorded with the lens and one without the lens.

\begin{table}[H]
\centering
\caption{Short \SI{2}{m} timed retest: lens vs. no lens.}
\label{tab:2mtest}
\resizebox{\textwidth}{!}{%
\begin{tabular}{@{}lrrrrrr@{}}
\toprule
Condition & Target dist [m] & Avg peak amp & Batch HR & Batch HR conf. & Weighted HR & Weighted HR conf. \\
\midrule
Plano-convex lens & 1.862 & 556 & 62.5 & 12.5 & 54.5 & 8.6 \\
No lens & 1.682 & 491 & 102.1 & 6.7 & 83.2 & 5.8 \\
\bottomrule
\end{tabular}%
}
\end{table}

The lens increased average peak amplitude only modestly (about \SI{13}{\percent}), so this was not a dramatic gain result. However, the lens case produced a much more plausible HR estimate than the no-lens case. This again supports the main argument of the report: \emph{amplitude alone is not the right decision metric}. A configuration can have only a small amplitude advantage yet still produce more believable physiology.

\section{Plots}
The generated plots are included below because the time-domain behavior is at least as informative as the summary tables.

\begin{figure}[p]
    \centering
    
    \caption{Night 1\_1: plano-convex lens. Radar HR/RR and heuristic sleep phases overlaid with Garmin reference data.}
\end{figure}

\begin{figure}[p]
    \centering
    
    \caption{Night 2: FZP lens. This night had high dominant-return amplitude, but the strongest reflector was usually not at the tracked target distance.}
\end{figure}

\begin{figure}[p]
    \centering
    
    \caption{Night 3: flat cover / effectively no lens. The recording was interrupted, but the HR agreement with Garmin was the best of the three nights.}
\end{figure}

\begin{figure}[p]
    \centering
    
    \caption{Dominant-return peak amplitude across the three overnight recordings. This figure is useful as engineering context, but it should not be read as a direct measure of chest-signal strength.}
\end{figure}

\begin{figure}[p]
    \centering
    \begin{subfigure}[t]{0.49\textwidth}
        \centering
        
        \caption{Plano-convex lens at about \SI{2}{m}.}
    \end{subfigure}
    \hfill
    \begin{subfigure}[t]{0.49\textwidth}
        \centering
        
        \caption{No lens at about \SI{2}{m}.}
    \end{subfigure}
    \caption{Short timed retest used to probe whether the plano-convex lens behaves better when moved farther away to make aiming easier.}
\end{figure}

\section{Discussion}
\subsection{What the Garmin comparison says}
The overnight Garmin comparison is the strongest result available from the current data. RR agreement remained fairly close to Garmin on all three nights, typically within about \SI{0.5}{brpm}. HR was more discriminative: the flat-cover night agreed best with Garmin, while the lensed nights under-read HR by roughly \SIrange{2}{3}{bpm} on average.

\subsection{What the peak amplitudes do \emph{not} say}
The very large raw amplitudes on nights 2 and 3 are not evidence that those nights had stronger physiological returns from the chest. In fact, the target-alignment table suggests the opposite interpretation: the strongest reflector was often spatially separated from the tracked target by \SIrange{0.12}{0.32}{m}. This is fully consistent with a bed-edge setup where the mattress, bed frame, or nearby bedding can dominate the return.

\subsection{What can still be said about the lenses}
The data do not justify a simple ``higher amplitude = better lens'' conclusion. Instead, the results suggest the following:
\begin{itemize}
    \item the plano-convex lens in night 1\_1 may have been mis-aimed and/or used at a geometry that did not place the subject well within the main lobe,
    \item the FZP night produced a very strong dominant reflector but poor target alignment, so the large peak was likely not the subject,
    \item the flat-cover night produced the best HR agreement, which means the simpler configuration was the most reliable in this specific mounting arrangement,
    \item the short \SI{2}{m} retest suggests that moving the lens farther away may improve practical aiming, but the current retest still showed only a small raw amplitude gain.
\end{itemize}

\subsection{REM-to-deep transitions}
The direct REM$\rightarrow$deep transitions seen in the radar heuristic but not in Garmin indicate that the stage classifier should still be treated as exploratory. The HR/RR overlays appear more trustworthy than the exact radar stage labels at this point.

\subsection{Limitations}
This comparison has several limitations:
\begin{itemize}
    \item only one main overnight recording per lens condition,
    \item night 3 was interrupted,
    \item the radar geometry was not fixed in a controlled mechanical jig,
    \item Garmin is a practical consumer reference, not polysomnography,
    \item the dominant-return amplitude was confounded by bed-edge reflections.
\end{itemize}

\section{Overall findings}
The main conclusions of the current experiment are as follows:
\begin{enumerate}
    \item \textbf{Garmin agreement is the correct primary lens-comparison metric for this dataset.} It is substantially more informative than raw dominant-return amplitude.
    \item \textbf{Night 3 (flat cover / effectively no lens) produced the best overnight HR agreement with Garmin.} Nights 1\_1 and 2 under-read HR more clearly.
    \item \textbf{RR tracking was relatively robust across all three nights.} The radar stayed close to Garmin RR regardless of front-end condition.
    \item \textbf{The huge peak amplitudes in nights 2 and 3 were probably dominated by non-subject reflectors.} Target-distance mismatch makes this interpretation much more likely than a true chest-signal gain explanation.
    \item \textbf{The plano-convex lens should be retested with easier aiming geometry.} The later \SI{2}{m} retest supports this plan: the lens did not produce a huge amplitude gain, but it did produce more plausible HR behavior than the no-lens control.
\end{enumerate}

The most useful next step is therefore not to optimize for raw peak amplitude, but to repeat the lens tests with tighter mechanical control, a better defined subject distance, and repeated Garmin-referenced nights per condition.

\begin{thebibliography}{9}
\bibitem{acconeerlens}
Acconeer,
\emph{Lens design}, A121 integration documentation,
\url{https://docs.acconeer.com/en/latest/integration/lens_design.html}.
Key points used here: dielectric lenses shape the beam and increase gain;
plano-convex and FZP example lenses are provided; focal distance may need
tuning because housing/radome effects can shift the gain maximum.
\end{thebibliography}

\end{document}

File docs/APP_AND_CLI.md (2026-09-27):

# RespiNet App and CLI Guide

This guide documents the unified desktop app, supported sensors, recording outputs, and useful CLI commands.

## Setup

Install/update the Python environment with `uv`:

```powershell
uv sync
```

The project dependencies include:

- `PySide6` - Qt desktop UI
- `pyqtgraph` - interactive live/history plots
- `pyserial` - ESP32/serial devices
- `acconeer-exptool[app]` - Acconeer A121 low-level Python API
- `numpy`, `pandas`, `scipy`, `matplotlib` - analysis and offline plots

## Supported sensors

### HB100 radar via ESP32 ADC

Use this for the existing analog HB100 radar pipeline. The current ESP32
firmware streams strict ASCII at 230400 baud and a stable 250 Hz in CSV-like
serial rows:

```text
Timestamp_ms,RawADC,Voltage_mV
```

Default output folder:

```text
data/raw/radar/
```

### Acconeer / Waveshare A121 radar

Use this for the Waveshare A121 Range Sensor connected over USB-C/UART.

Important: the Waveshare board exposes two serial ports. Use the first one, usually shown as Interface A:

- Windows: `USB-Enhanced-SERIAL-A CH342 (COMx)`
- Linux/macOS: usually `/dev/ttyUSB0` or similar

The app captures Sparse IQ data from the A121 and stores per-frame:

```text
Timestamp_ms,Frame,PeakDistance_m,PeakAmplitude,PeakPhase_rad,MeanAmplitude,
Distances_m,Amplitude,Phase,Real,Imag
```

`Distances_m`, `Amplitude`, `Phase`, `Real`, and `Imag` are JSON arrays in the CSV so the full distance profile can be replayed later.

Default output folder:

```text
data/raw/a121/
```

### IMU

Use this for the ESP32/LSM6DS3 comparison path. The current firmware streams a
sample counter and its own microsecond clock before the six axes; the desktop
CSV preserves both of them as well as the host arrival time:

```text
Time_ms,HostTime_ms,DeviceTime_us,SampleIndex,ax,ay,az,gx,gy,gz
```

`Time_ms` is the device clock aligned to the host epoch at first reception.
For legacy six-axis firmware rows, the same reader remains compatible, but the
counter and device-clock columns are empty and exact UART-loss detection is not
available.

Default output folder:

```text
data/raw/imu/
```

### iPhone IMU over BLE

Use this with the native SwiftUI companion app in `ios/RespiPhoneIMU/`. The iPhone advertises a custom BLE service named `RespiPhoneIMU`, samples CoreMotion at 20-100 Hz, and sends compact binary batches. The desktop receiver expands those batches to the same IMU CSV schema used by the ESP32 path:

```text
Time_ms,ax,ay,az,gx,gy,gz
```

Acceleration is in `g`, gyroscope values are in `deg/s`, and `Time_ms` is aligned to the desktop host clock from the first received phone sample.

## Unified desktop app

Open the app:

```powershell
uv run respi app
```

Open the app with a specific sensor and port:

```powershell
uv run respi app --sensor radar --port COM6
uv run respi app --sensor a121 --port COM3
uv run respi app --sensor imu --port COM6
uv run respi app --sensor iphone-imu
```

Available app sensor choices:

- `HB100 Radar`
- `A121 Radar`
- `IMU`
- `iPhone IMU (BLE)`

### App controls

Common controls:

- Sensor selector
- Serial port selector with refresh button
- Baud rate selector for ESP32-based sensors
- Recording target:
  - `CSV + SQLite`
  - `CSV only`
  - `SQLite only`
- Live window length in seconds
- Start/Stop recording buttons

A121-specific controls:

- `A121 target selection` - uses Acconeer's breathing reference state machine/presence-distance selector by default
- `A121 gate display` - overlays the currently selected compact range segment on the amplitude plot
- `A121 breath phases` - automatically shades detected inhale/exhale phases on A121 respiration plots and saves a `*_breath_annotations.csv` sidecar for CSV recordings
- `Offline/fallback gate` - compact segment width used only when no recorded/live Acconeer selected range is available
- `A121 start` - start distance in meters, e.g. `0.20 m`
- `A121 end` - end distance in meters, e.g. `1.50 m`
- `A121 profile` - Acconeer profile `1..5`; profile 3 is the default breathing-reference profile
- `A121 HWAAS` - hardware averaging; higher values reduce noise but reduce update rate
- `A121 sweeps` / `A121 fps` - defaults are 16 sweeps at 20 Hz to avoid UART backlog and GUI lag

### App graphs

Graphs are rendered with `pyqtgraph` and are interactive:

- drag to pan
- mouse wheel to zoom
- right-click for plot options

Live graph behavior:

- HB100: voltage over time + FFT
- A121: latest amplitude vs distance plus selectable filtered vitals, rate FFT, or raw IQ/phase view. The live time-domain A121 traces use stateful causal filters, so previous samples are not recomputed as new frames arrive.
- IMU: accelerometer axes + gyroscope axes

### Live stats

The stats panel shows sensor-dependent metrics:

- HB100:
  - sample rate
  - estimated respiration-band BPM
  - peak frequency
  - Doppler speed estimate
- A121:
  - frame rate
  - peak distance/amplitude and range gate
  - compact range-bin count and signal-quality index
  - Acconeer `BreathingProcessor` respiration-rate estimate
  - heart candidate confidence
  - Kalman-gated tracked heart estimate, shown as `acquiring` until stable enough
- IMU:
  - sample rate
  - respiration-band estimate
  - heart-band estimate
  - accelerometer RMS
  - gyroscope RMS

### Recordings tab

The `Recordings` tab can open:

- saved CSV files from `data/raw/radar/`, `data/raw/a121/`, and `data/raw/imu/`
- sessions stored in SQLite

SQLite database path priority:

1. `RESPI_RECORDINGS_DB_PATH` (or `RESPI_DB_PATH`) if set.
2. `E:/respi_recordings.sqlite3` on Windows, when that file exists.
3. `data/respi_recordings.sqlite3` in the project folder as the macOS/Linux-safe fallback.

The project-local fallback database is ignored by Git.

## CLI commands

Show all commands:

```powershell
uv run respi --help
```

List serial ports:

```powershell
uv run respi ports
```

Open the unified app:

```powershell
uv run respi app --sensor radar --port COM6
uv run respi app --sensor a121 --port COM3
uv run respi app --sensor imu --port COM6
```

Test the A121 without opening the UI:

```powershell
uv run respi test-a121 --port COM3 --frames 20 --start-m 0.2 --end-m 1.0 --profile 3 --hwaas 32 --sweeps-per-frame 16 --frame-rate-hz 20
```

Record a real-data A121 test CSV. Omit `--seconds` to record until Ctrl+C; if supplied, `--seconds` has no upper cap:

```powershell
uv run respi record-a121-test --port COM3 --label foil-chest
uv run respi record-a121-test --port COM3 --seconds 60 --label foil-chest
# Configure A121 range/profile/HWAAS/sweeps/frame-rate explicitly:
uv run respi record-a121-test --port COM3 --seconds 80 --label 80hr --start-m 0.20 --end-m 1.50 --profile 3 --hwaas 32 --sweeps-per-frame 16 --frame-rate-hz 20
# Automatic breath phase annotations, avoiding key-press vibration artifacts:
uv run respi record-a121-test --port COM3 --seconds 80 --label auto-breath --auto-breaths
# Manual breath phase markers are still available: press i for inhale start/end, o for exhale start/end.
uv run respi record-a121-test --port COM3 --seconds 80 --label breath-marked --mark-breaths --inhale-key i --exhale-key o
# Generate automatic breath annotations for an existing A121 CSV:
uv run respi annotate-a121-breaths data/raw/a121/a121_test_80s_auto-breath_YYYY-MM-DD_HH-MM-SS.csv
# Alias:
uv run respi capture-a121 --port COM3 --label foil-chest
uv run respi capture-a121 --port COM3 --seconds 60 --label foil-chest
```

This saves a new non-overwriting file under `data/raw/a121/`, for example `a121_test_60s_foil-chest_YYYY-MM-DD_HH-MM-SS.csv`. `--auto-breaths` or `annotate-a121-breaths` saves a sidecar `*_breath_annotations.csv` in the same five-column format as manual markers: `Timestamp_ms,Elapsed_s,Frame,Event,Key`. Events are `inhale_start`, `inhale_end`, `exhale_start`, and `exhale_end`; automatic rows use `Key=auto`. Manual `--mark-breaths` is still supported, but it can shake the sensor if key presses are hard.

Record an overnight/sleep A121 CSV. The sleep command streams rows directly to disk instead of keeping the full night in RAM. Omit `--hours` to record until you manually stop with Ctrl+C; include it only as a safety limit. By default, stopping the sleep recording also runs gated vitals extraction, classifies radar sleep phases, computes a Garmin-like radar sleep score, and writes a plot plus CSV/JSON sidecars under `data/plots/`.

```powershell
uv run respi record-a121-sleep --port COM3 --label sleep-night-1
uv run respi record-a121-sleep --port COM3 --label sleep-night-1 --hours 8
# Disable automatic post-processing:
uv run respi record-a121-sleep --port COM3 --label sleep-night-1 --no-auto-analyze
# Keep automatic vitals analysis but skip the sleep/comparison plot:
uv run respi record-a121-sleep --port COM3 --label sleep-night-1 --no-auto-plot
# Include Garmin FIT overlay after recording if you already have exported FIT files:
uv run respi record-a121-sleep --port COM3 --label sleep-night-1 --garmin-fit path\to\WELLNESS.fit --garmin-fit path\to\SLEEP_DATA.fit
```

Offline A121 sleep analysis and Garmin FIT comparison can be run later on existing files:

```powershell
# Full raw A121 CSV -> gated HR/RR trend -> sleep phases/score/plot
uv run respi analyze-a121-sleep data\raw\a121\a121_sleep_YYYY-MM-DD_HH-MM-SS.csv
# Existing gated trend CSV -> radar-only phase/score plot
uv run respi plot-a121-sleep data\plots\a121_sleep_YYYY-MM-DD_HH-MM-SS_gated_sleep_vitals.csv
# Existing trend + one Garmin FIT file or a directory of FIT files; timestamps are aligned in local time
uv run respi plot-a121-sleep data\plots\a121_sleep_YYYY-MM-DD_HH-MM-SS_gated_sleep_vitals.csv --garmin-fit path\to\GarminExportDir
uv run respi plot-a121-sleep data\plots\a121_sleep_YYYY-MM-DD_HH-MM-SS_gated_sleep_vitals.csv --garmin-fit path\to\WELLNESS.fit --garmin-fit path\to\SLEEP_DATA.fit
# Vitals-only plot with no phase/score panel
uv run respi plot-a121-sleep data\plots\a121_sleep_YYYY-MM-DD_HH-MM-SS_gated_sleep_vitals.csv --no-sleep-phases
# Decode Garmin FIT tables only
uv run respi decode-garmin-fit path\to\WELLNESS.fit path\to\SLEEP_DATA.fit --stem my_sleep
```

Reusable code/scripts:

- Garmin FIT decoding: `src/respi_net/garmin_fit.py`, CLI `respi decode-garmin-fit`
- Radar sleep phases/scoring/plotting: `src/respi_net/a121_sleep.py`, CLI `respi plot-a121-sleep`
- Raw overnight A121 gated vitals extraction: `tools/analyze_a121_sleep_vitals_gated.py`, CLI `respi analyze-a121-sleep`
- Direct repository wrapper: `tools/plot_a121_garmin_sleep_overlay.py`

Expected output looks like:

```text
A121 session started: 0.200-1.010 m, 55 points, profile 3, HWAAS 32.
Frame 000 | peak=0.458 m | amp=192.3 | phase=2.10 rad
```

Capture HB100 radar from serial until Ctrl+C:

```powershell
uv run respi capture-radar --port COM6
```

Capture IMU from serial until Ctrl+C:

```powershell
uv run respi capture-imu --port COM6
```

Scan for and capture iPhone IMU data over BLE:

```powershell
uv run respi iphone-imu-devices
uv run respi capture-iphone-imu --seconds 60
uv run python tools/imu_lsm6ds3_iphone_guided_experiment.py --lsm-port /dev/cu.usbserial-XXXX
```

`imu_lsm6ds3_iphone_guided_experiment.py` is a separate guided protocol for
the four supine LSM6DS3--iPhone trials. It stores both sensor files, shared
cue timestamps, loss diagnostics and a manifest; Esc deletes the active
trial, while a completed one can be discarded and repeated before acceptance.

Generate an offline HB100 radar plot:

```powershell
uv run respi plot-radar data\raw\radar\radar_raw_YYYY-MM-DD_HH-MM-SS.csv
```

Generate an offline IMU plot:

```powershell
uv run respi plot-imu data\raw\imu\respiratory_6axis_raw_YYYY-MM-DD_HH-MM-SS.csv
```

Batch-generate plots:

```powershell
uv run respi batch-radar
uv run respi batch-imu
```

Compatibility alias:

```powershell
uv run respi live-radar --port COM6
```

`live-radar` now opens the unified app in HB100 radar mode.

## Breathing coach and pattern files

Every guided-breathing screen uses one coach panel and one pattern format. The
panel shows the whole session along the top as a timeline drawn the way the
lungs move: width is time, inhales (blue) climb, exhales (green) fall, holds
(red) stay high after an inhale and low after an exhale, and free breathing
(grey) or an empty scene (amber) are flat. Under it are the current cue with a
bar draining as the phase runs out and the seconds left, and the next cue. In the last three seconds of a long phase such
as a breath hold, the next cue is highlighted. The HB100/A121, A121 lens/foil
and LSM6DS3/iPhone recording tools all use it, and it can also run on its own:

```powershell
uv run respi coach                    # pick a pattern in the window
uv run respi coach box_breathing      # start with a named pattern
uv run respi coach path\to\mine.json   # any pattern file
uv run respi coach --list             # list configs/breathing_patterns
uv run respi coach --print paced_12_hold  # check a file: expanded schedule
```

Space starts, pauses and resumes; Esc stops. `Wczytaj ponownie` reloads the
selected file after you edit it, and the cue grows with the window, so it can
run full screen.

Patterns live in `configs/breathing_patterns/*.json`:

```json
{
  "name": "Rytm 12/min + wstrzymanie",
  "description": "Optional text shown above the coach.",
  "blocks": [
    {"kind": "normal", "duration_seconds": 10},
    {"kind": "paced", "cycles": 7, "inhale_seconds": 2, "exhale_seconds": 3},
    {"kind": "hold", "duration_seconds": 15},
    {"kind": "repeat", "times": 2, "blocks": [
      {"kind": "paced", "cycles": 3, "inhale_seconds": 4, "exhale_seconds": 6},
      {"kind": "normal", "duration_seconds": 20, "label": "Przerwa"}
    ]}
  ]
}
```

- Single phases: `settle`, `normal`, `inhale`, `exhale`, `hold`,
  `interference`, each with `duration_seconds` and optional `cue`, `detail`
  and `label` (the name on the timeline).
- `paced`: `cycles`, `inhale_seconds`, `exhale_seconds`, and optionally
  `hold_after_inhale_seconds` / `hold_after_exhale_seconds` (box breathing),
  `inhale_cue`, `exhale_cue`, `hold_cue`, `inhale_detail`, `exhale_detail`,
  `hold_detail`, `label`.
- `repeat`: `times` and nested `blocks`.

Unknown keys are errors, not silently ignored, and every error names the block
and key it is about. `paced_12_hold` and `natural_hold` are the protocols the
recording tools use. The recorded cue CSVs and manifests keep their previous
columns, and tests pin both protocols to the schedule already recorded. An A121
experiment config can name a pattern with `"breathing_pattern": "paced_12_hold"`
instead of listing inline `breathing_protocol` blocks. The inline blocks use
the same format.

## A121 implementation notes

The A121 capture code uses Acconeer's low-level client:

```python
from acconeer.exptool import a121
client = a121.Client.open(serial_port="COM3")
```

Internally, the app creates an `a121.SensorConfig` using approximate distance-to-point conversion:

```text
start_point ~= start_m / 0.0025
num_points  ~= (end_m - start_m) / (0.0025 * step_length)
```

After `setup_session`, the actual physical distance bins are computed from Acconeer metadata via `get_distances_m(...)`.

For every frame:

- raw complex Sparse IQ frame is read
- amplitude is computed with `np.abs(...)`
- phase is computed with `np.angle(...)`
- strongest amplitude bin becomes `PeakDistance_m`
- full arrays are saved as JSON strings in CSV/SQLite
- Acconeer reference-app state, presence distance, selected compact range, and breathing rate are saved per frame

For live A121 respiration, target acquisition/reacquisition follows Acconeer's breathing reference app state machine and presence-distance selection. New CSV/SQLite recordings persist that Acconeer selection, so history/offline analysis reuses the same selected gate instead of rediscovering a weaker host-side gate from averaged IQ. The `Offline/fallback gate` is now only for disabled/unavailable Acconeer selection or very old/core-only files. Heart-rate extraction is not provided by Acconeer here; the app treats it as an experimental, conservatively gated candidate. The A121 result buffer is limited to about `num_points * sweeps_per_frame <= 4095`; the app automatically reduces sweeps/frame or increases step length when a requested range would exceed sensor/serial limits.

## Troubleshooting

### A121 does not connect

1. Run:

   ```powershell
   uv run respi ports
   ```

2. Pick the `USB-Enhanced-SERIAL-A CH342` port, not `SERIAL-B`.
3. Close Acconeer GUI or any other program that may be using the port.
4. Try the CLI test:

   ```powershell
   uv run respi test-a121 --port COM3 --frames 5
   ```

### No ESP32 data appears

- Check the correct COM port.
- Check firmware matches selected app sensor.
- Confirm the sensor-specific baud rate: HB100 defaults to `230400`, while the
  ESP32 IMU uses `115200`.
- Use `uv run respi ports` to verify the port is visible.

### Empty or noisy plots

- For A121, narrow the range with `A121 start` / `A121 end`.
- Increase A121 HWAAS to reduce noise.
- Try A121 profile 3 first, then adjust profiles for closer/farther targets.
- For HB100, check amplifier clipping and ADC wiring.

## Source files

Main implementation files:

```text
src/respi_net/app.py      # Unified Qt/pyqtgraph app
src/respi_net/a121.py     # Acconeer A121 Sparse IQ capture
src/respi_net/radar.py    # HB100 radar analysis/capture
src/respi_net/imu.py      # IMU analysis/capture
src/respi_net/iphone_imu.py # iPhone BLE IMU batch receiver
src/respi_net/cli.py      # Click CLI commands
src/respi_net/breathing.py        # Breathing pattern files: format, loading, timeline lookups
src/respi_net/breathing_coach.py  # Coach panel shared by every guided-breathing screen
src/respi_net/coach_app.py        # Standalone `respi coach` window
src/respi_net/paths.py    # Data/output paths
```

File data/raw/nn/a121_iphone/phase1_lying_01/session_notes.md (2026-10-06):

# Notes for phase1_lying_01
- Phase 1 recording 1: pattern nn_self_3min, lying (exact posture to be confirmed by the user), distance 45 cm, radar on the chest,
  phone on the lower ribs. Mostly regular breathing for ~100 s, one long hold at ~121-137 s, a deep breath at ~170 s.
- Posture (from the user): half on the side; radar close but aimed too high on the chest. Repeated as phase1_halfside_02.

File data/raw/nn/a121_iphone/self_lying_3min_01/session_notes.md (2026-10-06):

# Notes for self_lying_3min_01
- Pattern nn_self_3min (10 s settle + 170 s unguided). Lying, distance 45 cm (radar showed the chest at ~0.36-0.39 m),
  radar aimed at the chest (strong signal), phone on the other side. No deliberate holds were made.

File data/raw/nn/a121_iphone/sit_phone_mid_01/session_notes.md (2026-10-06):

# sit_phone_mid_01 (2026-10-04)
Pattern phone_site_1m, sitting, radar ~0.6 m from the chest (manifest says 50 cm: typed value, real peak echo at 0.60-0.62 m), aimed at the middle / slightly above.
Phone strapped on the middle of the chest, screen towards the radar (in the beam). Recorded second, same position.
Purpose: does a phone in the beam change the radar, and does a mid-chest phone keep the level through a deep-inhale hold. Result: NOTES_PHONE_PILOT.md, tools/plot_phone_site.py.

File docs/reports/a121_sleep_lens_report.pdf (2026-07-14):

## A121 Sleep Radar Lens Experiments

Overnight comparison of plano-convex, FZP, and flat-cover configurations with Garmin reference data

June 2026

Abstract
This report summarizes three overnight A121 radar sleep recordings and two short follow-up bench tests performed while changing the front-end optical/mechanical configuration: a plano-convex lens (night 1_1), a Fresnel zone plate (FZP) lens (night 2), and a flat cover that behaved approximately like a no-lens condition (night 3). Garmin heart-rate (HR), respiration-rate (RR), and sleep-stage overlays were used as the main external reference. A key result of the analysis is that raw radar peak_amplitude cannot be interpreted as chest-signal strength in this setup, because the radar was placed near the bed edge and the dominant reflector was often closer than the tracked subject distance. The most meaningful comparison therefore comes from Garmin agreement and from the plausibility/stability of the radar-derived sleep metrics. Night 3, despite having no focusing lens, produced the closest HR agreement to Garmin, while nights 1_1 and 2 showed larger HR bias and heuristic REM→deep transitions not present in Garmin. The short 2 m retest showed only a small amplitude increase with the plano-convex lens compared with no lens, but the lens produced more plausible HR estimates.

## 1 Background and framing

Acconeer’s lens design documentation notes that dielectric lenses are mainly used to shape the radiation pattern, increase gain, narrow the beamwidth, and in some cases suppress unwanted reflections. The same documentation presents both a plano-convex example lens and an FZP example lens for A121-class hardware, and explicitly notes that focal distance may require tuning because the optimum can shift due to the radome, housing, material tolerances, and nearby mechanics. This point is directly relevant here because the experiments were performed in a bedroom geometry with the radar mounted near the bed edge rather than in a controlled freespace test fixture.

Interpretation rule used throughout this report.

Raw peak_amplitude is treated only as a dominant-return engineering metric, not as a direct proxy for chest reflection strength or physiological signal quality. The reason is that the strongest radar return could originate from the bed edge, mattress, bedding, or another static reflector rather than the subject.

This framing is important because the raw peak amplitudes differed by more than an order of magnitude between nights, yet the strongest returns were often not spatially aligned with the tracked target distance.

## 2 Experimental conditions

Table 1 summarizes the three overnight recordings used in the comparison. Night 3 was interrupted, so it contains only about three hours of usable data. The Garmin overlay plots and the radar sleep-score JSON sidecars were generated for all three nights.

Table 1: Overnight recordings and hardware condition.

Night | Date | Front-end condition | Recording length | Note
1_1 | 2026-06-08 | Plano-convex lens | 6.95 h | Full night
2 | 2026-06-09 | FZP lens | 6.48 h | Full night
3 | 2026-06-10 | Flat cover / effectively no lens | 3.56 h | Interrupted recording

The A121 lens documentation is useful for interpreting these tests:

- dielectric lenses can increase gain and narrow the beam,
- the plano-convex and FZP lenses are both valid A121-compatible example designs,
- FZP lenses are mechanically thinner and their thickness is less coupled to diameter,
- the effective focal point can shift because of radome/housing effects and nearby mechanics.

These points make aiming and lens-to-radar spacing critical, especially in a bed-edge mounting geometry.

## 3 Analysis method

The overnight data were processed with the repository’s A121 sleep-analysis pipeline. For each night the following outputs were generated and used here:

- gated radar HR/RR trends,
- radar sleep-phase heuristic and radar sleep score,
- Garmin HR/RR overlays,
- radar sleep-parameter JSON sidecars,
- diagnostic comparison plots.

The following metrics were extracted:

1. radar sleep score, total sleep time, efficiency, and estimated resting HR,
2. mean and median HR/RR compared against Garmin,
3. sleep-stage duration sums (where available from the analysis session),
4. direct REM→deep transition counts,
5. dominant-return peak amplitude and its spatial alignment to the tracked target distance,
6. short timed lens vs. no-lens retest diagnostics at roughly 2 m.

Estimated resting HR was added to the automatic radar sleep JSON files and defined as the 10th percentile of quiet, non-awake radar HR windows inside the inferred sleep interval. This makes it more robust than taking a raw minimum while still approximating the lower resting envelope overnight.

## 4 Primary overnight results

### 4.1 Radar-only sleep summary

Table 2 summarizes the radar-inferred overnight sleep metrics.

Table 2: Radar sleep summary from the generated JSON sidecars.

Night | Score | Total sleep [min] Efficiency [%] Estimated resting HR [bpm] Quality
1_1 | 74 | 364.5 | 93.8 | 52.7 | Fair
2 | 71 | 342.5 | 95.0 | 51.9 | Fair
3 | 49 | 154.0 | 85.8 | 50.8 | Poor

Night 3 scored substantially worse mainly because the recording was interrupted and therefore short; the score was capped by duration. The estimated resting HR remained internally consistent across nights, staying in the low-50 bpm range.

### 4.2 Heart-rate comparison against Garmin

Garmin agreement is the most important outcome because it is much less sensitive to the bed-edge reflector issue than raw radar amplitude. Table 3 uses the sleep-only comparison windows discussed during the analysis session.

Table 3: Sleep-only heart-rate comparison between radar and Garmin.

Night | Radar mean | Radar median | Garmin mean | Garmin median | Mean bias | Median bias
[bpm] | [bpm] | [bpm] | [bpm] radar−Garmin | radar−Garmin
1_1 | 55.5 | 55.2 | 57.4 | 57.0 | -1.9 | -1.8
2 | 55.1 | 54.6 | 58.3 | 57.0 | -3.3 | -2.4
3 | 53.8 | 53.3 | 53.6 | 52.0 | +0.1 | +1.3

The HR comparison shows the clearest practical result of the experiment: the flat-cover night (night 3) matched Garmin best, while the two lensed nights under-read HR on average. This does not prove that the flat cover is universally better than a lens; it does show that the tested lens geometries did not automatically translate into better overnight physiological agreement in this mounting arrangement.

### 4.3 Respiration-rate comparison against Garmin

RR agreement was generally closer than HR agreement. Table 4 summarizes the values used during the analysis.

Table 4: Sleep-only respiration-rate comparison between radar and Garmin.

Night | Radar mean | Radar median | Garmin mean | Garmin median | Mean bias | Median bias
[brpm] | [brpm] | [brpm] | [brpm] radar−Garmin | radar−Garmin
1_1 | 13.6 | 14.2 | 14.0 | 14.4 | -0.4 | -0.2
2 | 14.6 | 14.9 | 14.2 | 14.4 | +0.4 | +0.5
3 | 14.3 | 14.3 | 14.0 | 14.1 | +0.3 | +0.2

RR stayed within about half a breath per minute of Garmin on average for all three nights. This is a stronger and more stable result than the raw peak-amplitude comparison.

### 4.4 Sleep-stage duration comparison

For nights 1_1 and 2, the analysis session retained quantitative radar-vs-Garmin sleep-stage duration sums extracted from the Garmin FIT stage data. These values are shown in Table 5. Night 3 was interrupted and is therefore discussed primarily through the overlay plot and radar-only sleep summary.

Table 5: Sleep-stage duration sums for nights 1_1 and 2. Positive difference means radar assigned more time to that stage than Garmin.

Night | Source | Awake [min] Light [min] Deep [min] REM [min]
1_1 | Radar | 24.0 | 212.5 | 78.5 | 73.5
1_1 | Garmin | 40.0 | 222.0 | 57.0 | 47.0
1_1 | Difference | -16.0 | -9.5 | +21.5 | +26.5
2 | Radar | 18.0 | 191.0 | 58.0 | 93.5
2 | Garmin | 5.0 | 211.0 | 18.0 | 117.0
2 | Difference | +13.0 | -20.0 | +40.0 | -23.5

Two additional stage-related observations were important:

- Nights 1_1 and 2 contained direct radar REM→deep transitions (two such transitions on each night), while Garmin showed zero direct REM→deep transitions in those same nights.
- This suggests that at least part of the radar stage disagreement came from the heuristic classifier rather than from the raw HR/RR tracking alone.

## 5 Why peak amplitude must be interpreted carefully

The raw peak-amplitude plot across nights is striking: the median dominant return rises from roughly 1.7×10³

in night 1_1 to 1.75×10⁴

in night 2 and 2.36×10⁴
in night 3. However, Table 6 shows why this cannot be interpreted as “better chest signal”.

Table 6: Dominant-return amplitude and target-alignment diagnostics from the gated sleep-vitals CSV files.

Night | Peak amp median | Peak amp mean | Median target dist | Median peak dist | Median |∆d| Fraction with |∆d| ≤0.10 m
| [a.u.] | [a.u.] | [m] | [m] | [m] | [-]
1_1 | 1665.2 | 3079.7 | 0.37 | 0.15 | 0.16 | 0.316
2 | 17515.5 | 17659.7 | 0.44 | 0.12 | 0.32 | 0.012
3 | 23574.3 | 23240.3 | 0.22 | 0.10 | 0.12 | 0.384

The median dominant-return distance was much closer than the tracked target distance on all nights, especially on night 2. The FZP night is the clearest example: despite a median peak amplitude above 1.7 × 10⁴
, only about 1.2 % of windows had the dominant peak within 10 cm of the target. This makes it highly likely that the large peak came from the bed edge or another nearby reflector rather than from the subject.
This is the reason for the specific presentation used in this report:
1. Garmin HR/RR agreement is treated as the primary outcome,
2. sleep-stage agreement is treated as the secondary outcome,
3. raw peak amplitude is treated only as a contextual engineering variable.

## 6 Short follow-up retest at approximately 2 m

A short retest was performed after the overnight analysis to check whether the plano-convex lens behaved more sensibly at a longer distance, where aiming is easier. One 90 s sample was recorded with the lens and one without the lens.

Table 7: Short 2 m timed retest: lens vs. no lens.

Condition | Target dist [m] Avg peak amp | Batch HR | Batch HR conf. | Weighted HR | Weighted HR conf.
Plano-convex lens | 1.862 | 556 | 62.5 | 12.5 | 54.5 | 8.6
No lens | 1.682 | 491 | 102.1 | 6.7 | 83.2 | 5.8

The lens increased average peak amplitude only modestly (about 13 %), so this was not a dramatic gain result. However, the lens case produced a much more plausible HR estimate than the no-lens case. This again supports the main argument of the report: amplitude alone is not the right decision metric. A configuration can have only a small amplitude advantage yet still produce more believable physiology.

## 7 Plots

The generated plots are included below because the time-domain behavior is at least as informative as the summary tables.

## 8 Discussion

### 8.1 What the Garmin comparison says

The overnight Garmin comparison is the strongest result available from the current data. RR agreement remained fairly close to Garmin on all three nights, typically within about 0.5 brpm. HR was more discriminative: the flat-cover night agreed best with Garmin, while the lensed nights under-read HR by roughly 2 bpm to 3 bpm on average.

### 8.2 What the peak amplitudes do not say

The very large raw amplitudes on nights 2 and 3 are not evidence that those nights had stronger physiological returns from the chest. In fact, the target-alignment table suggests the opposite interpretation: the strongest reflector was often spatially separated from the tracked target by 0.12 m to 0.32 m. This is fully consistent with a bed-edge setup where the mattress, bed frame, or nearby bedding can dominate the return.

### 8.3 What can still be said about the lenses

The data do not justify a simple “higher amplitude = better lens” conclusion. Instead, the results suggest the following:

- the plano-convex lens in night 1_1 may have been mis-aimed and/or used at a geometry that did not place the subject well within the main lobe,
- the FZP night produced a very strong dominant reflector but poor target alignment, so the large peak was likely not the subject,
- the flat-cover night produced the best HR agreement, which means the simpler configuration was the most reliable in this specific mounting arrangement,

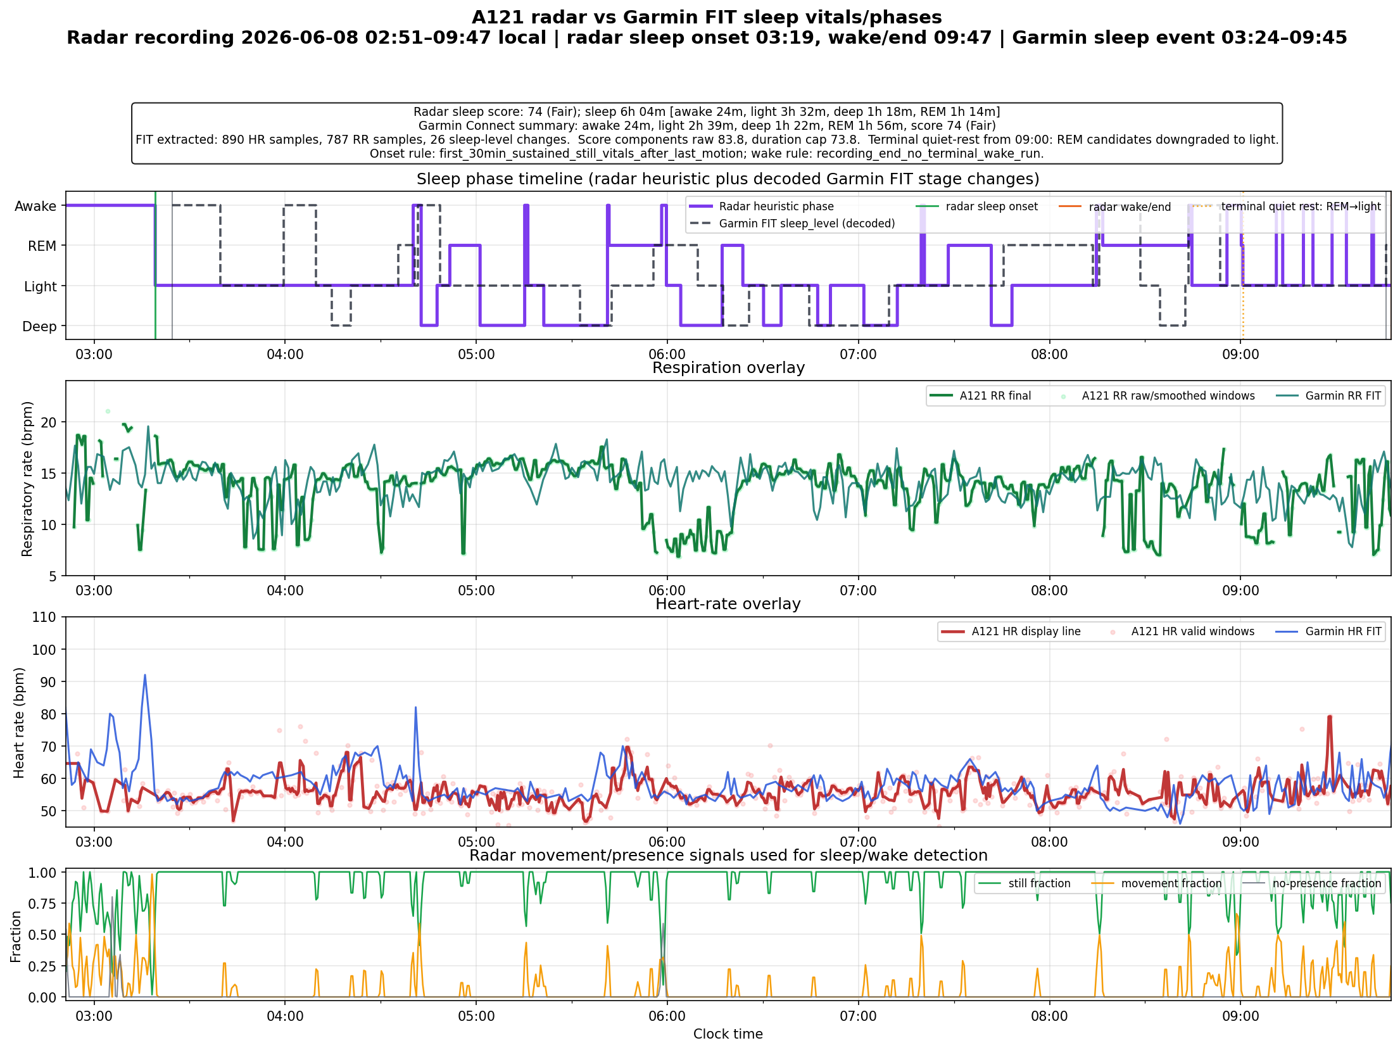
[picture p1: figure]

Figure 1: Night 1_1: plano-convex lens. Radar HR/RR and heuristic sleep phases overlaid with Garmin reference data.

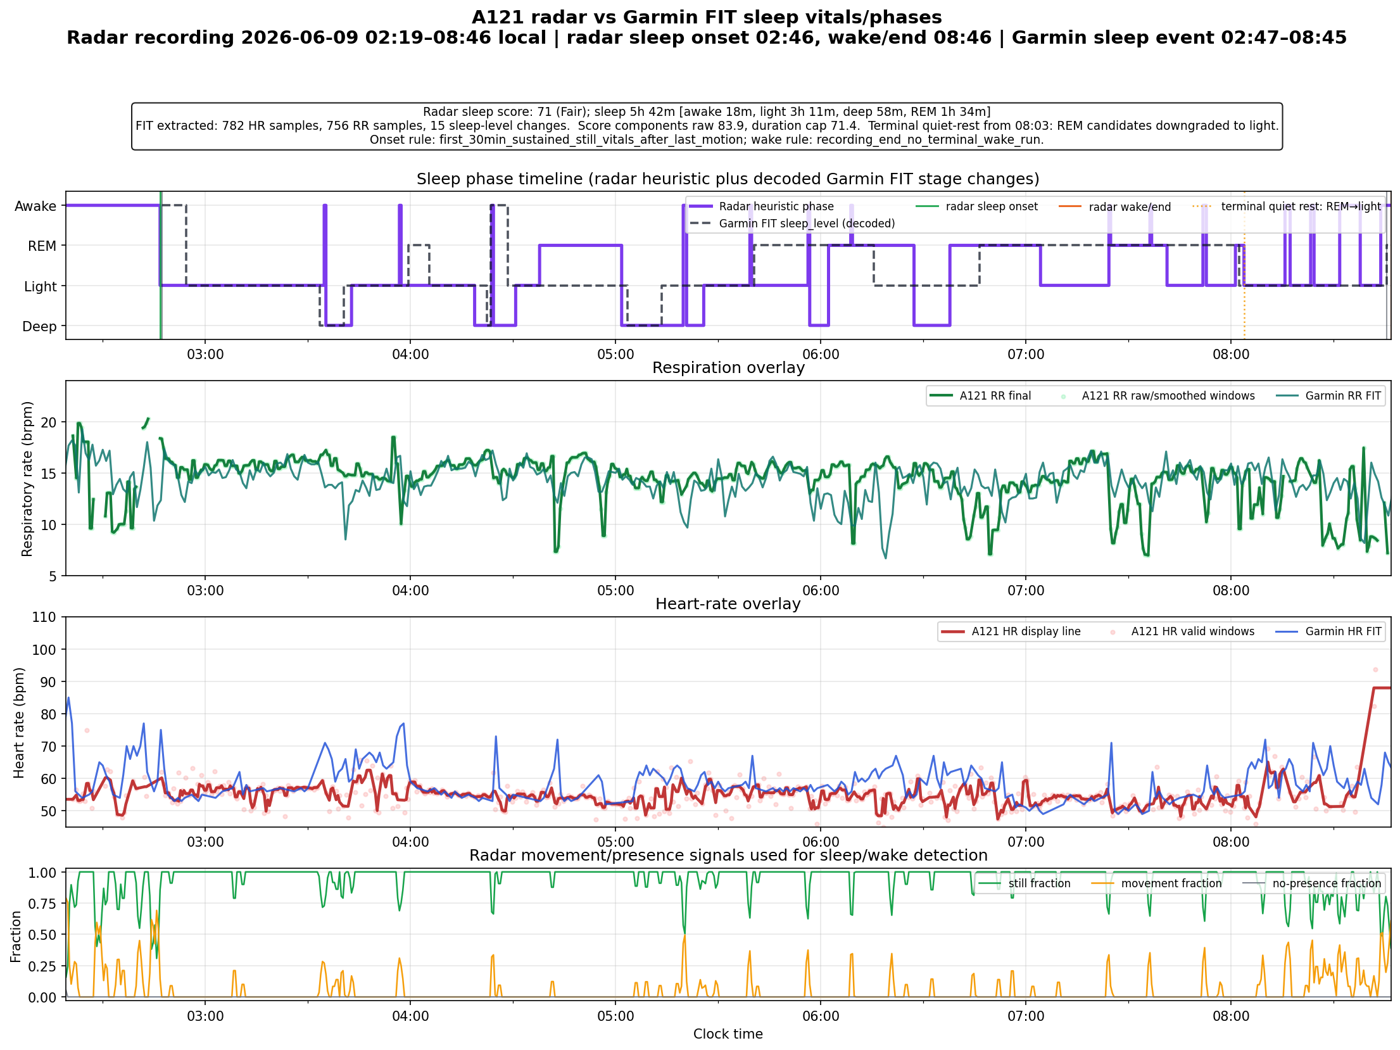
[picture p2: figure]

Figure 2: Night 2: FZP lens. This night had high dominant-return amplitude, but the strongest reflector was usually not at the tracked target distance.

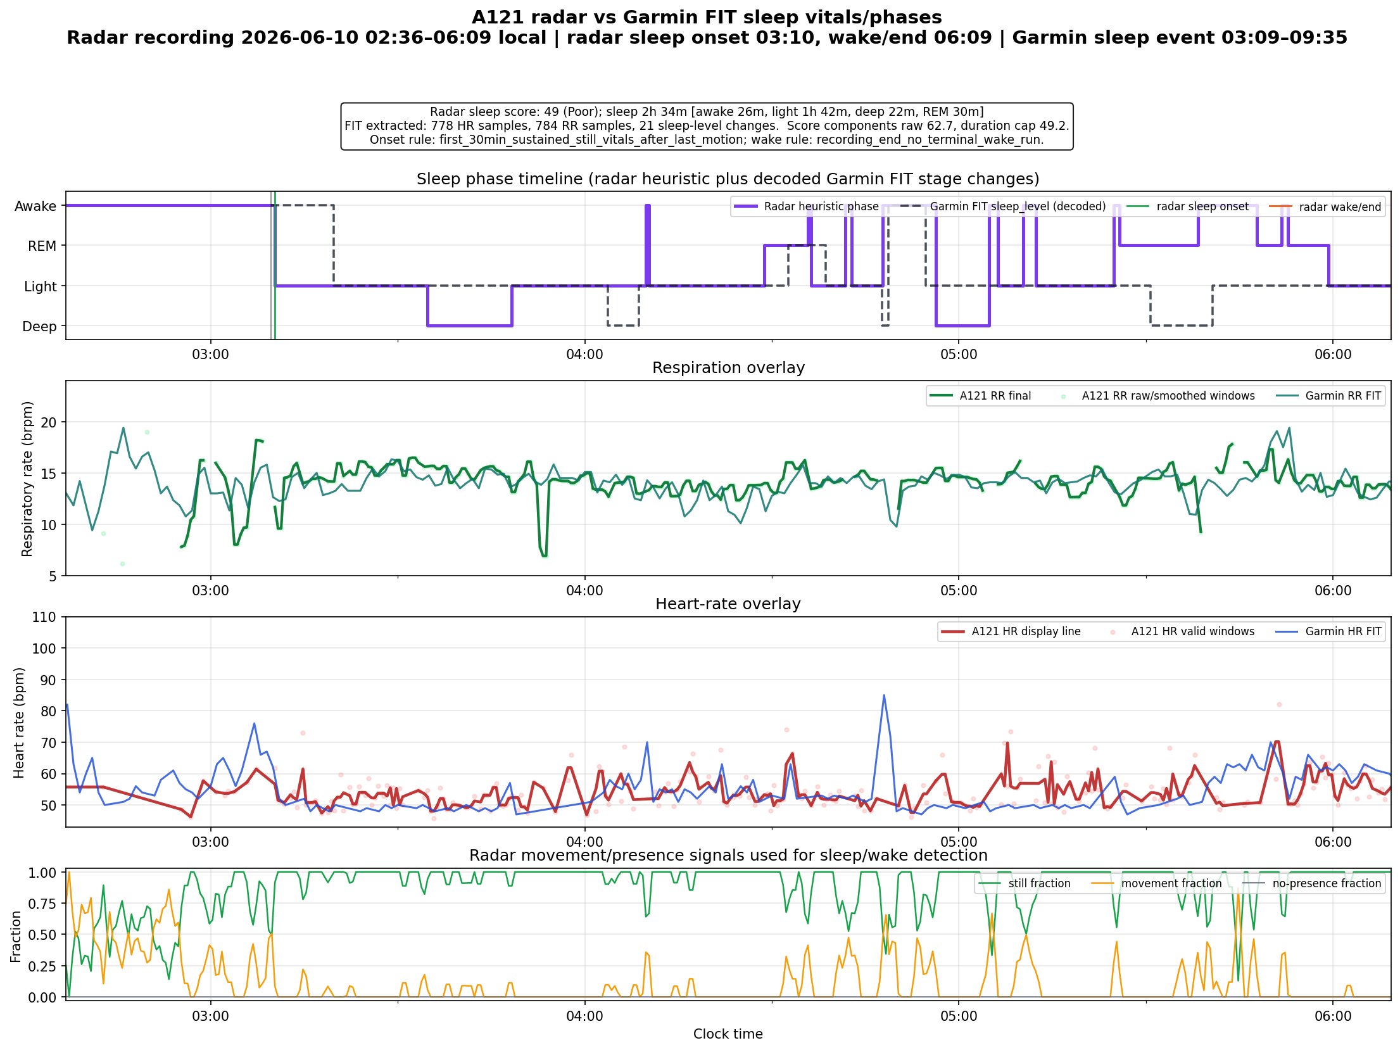
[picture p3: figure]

Figure 3: Night 3: flat cover / effectively no lens. The recording was interrupted, but the HR agreement with Garmin was the best of the three nights.

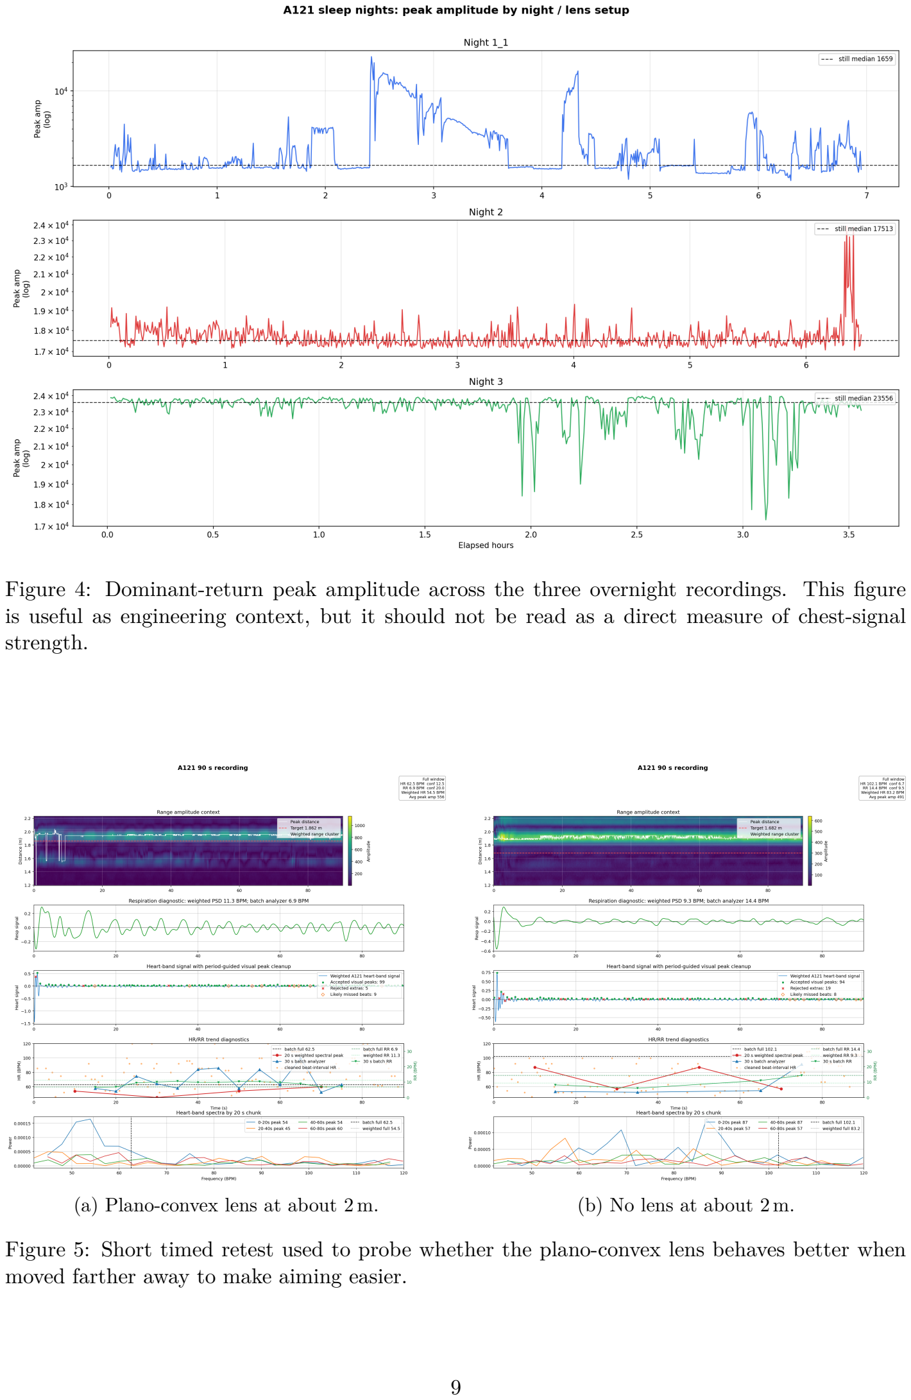
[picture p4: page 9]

Figure 4: Dominant-return peak amplitude across the three overnight recordings. This figure is useful as engineering context, but it should not be read as a direct measure of chest-signal strength.

(a) Plano-convex lens at about 2 m. | (b) No lens at about 2 m.

Figure 5: Short timed retest used to probe whether the plano-convex lens behaves better when moved farther away to make aiming easier.

- the short 2 m retest suggests that moving the lens farther away may improve practical aiming, but the current retest still showed only a small raw amplitude gain.

### 8.4 REM-to-deep transitions

The direct REM→deep transitions seen in the radar heuristic but not in Garmin indicate that the stage classifier should still be treated as exploratory. The HR/RR overlays appear more trustworthy than the exact radar stage labels at this point.

### 8.5 Limitations

This comparison has several limitations:

- only one main overnight recording per lens condition,
- night 3 was interrupted,
- the radar geometry was not fixed in a controlled mechanical jig,
- Garmin is a practical consumer reference, not polysomnography,
- the dominant-return amplitude was confounded by bed-edge reflections.

## 9 Overall findings

The main conclusions of the current experiment are as follows:

1. Garmin agreement is the correct primary lens-comparison metric for this dataset. It is substantially more informative than raw dominant-return amplitude.
2. Night 3 (flat cover / effectively no lens) produced the best overnight HR agreement with Garmin. Nights 1_1 and 2 under-read HR more clearly.
3. RR tracking was relatively robust across all three nights. The radar stayed close to Garmin RR regardless of front-end condition.
4. The huge peak amplitudes in nights 2 and 3 were probably dominated by nonsubject reflectors. Target-distance mismatch makes this interpretation much more likely than a true chest-signal gain explanation.
5. The plano-convex lens should be retested with easier aiming geometry. The later 2 m retest supports this plan: the lens did not produce a huge amplitude gain, but it did produce more plausible HR behavior than the no-lens control.

The most useful next step is therefore not to optimize for raw peak amplitude, but to repeat the lens tests with tighter mechanical control, a better defined subject distance, and repeated Garmin-referenced nights per condition.

## References

[1] Acconeer, Lens design, A121 integration documentation, https://docs.acconeer.com/en/latest/integration/lens_design.html. (https://docs.acconeer.com/en/latest/integration/lens_design.html) Key points used here: dielectric lenses shape the beam and increase gain; plano-convex and FZP example lenses are provided; focal distance may need tuning because housing/radome effects can shift the gain maximum.

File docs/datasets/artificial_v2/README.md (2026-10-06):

# Rozszerzone dane sztuczne z wcześniejszych nagrań — v2

Wygenerowano 2026-10-06 z tych samych źródeł, z których korzystał wcześniejszy
`tools/build_artificial_data.py`: 19 własnych nagrań A121 oraz 23 nagrania pasa
Szymańskiego. Pliki v1 pozostają zachowane. V2 jest **uzupełnieniem**, zawierającym wyłącznie
nowe augmentacje. Nie wykonano treningu.

## Podziały są tymczasowe

Większość docelowych danych nie jest jeszcze zebrana. Obecny przydział
train/val/test ma jedynie utrzymać techniczny format eksportu i pochodzenie
kopii. Nie jest zamrożonym planem walidacji i testowania ani podstawą do
raportowania końcowej jakości modelu. Builder odziedziczył przydziały v1,
żeby na tym etapie nie zmieniać równocześnie źródeł i podziału.

Po zebraniu danych należy ustalić podział po niezależnych sesjach i docelowym
zakresie osób. Następnie ponownie wybrać bank szumu z treningu i wygenerować
wszystkie kopie oraz okna. Oryginał, jego kopie i szum pozyskany z niego muszą
pozostać po jednej stronie tego podziału. Sama zmiana pola `split` w gotowych
oknach nie usuwa przecieku. Ta sama zasada dotyczy
[nowych oznaczeń bliskiego radaru](../radar_close_v1/README.md).

## Przenoszenie etykiet

Źródłem są **istniejące oznaczenia przebiegu źródłowego**, przed dodaniem
nowego szumu i dryfu. Nie uruchamiamy detektora ani nowego oznaczania na
zniekształconej kopii. Źródło nie jest idealnie czyste: ma swój rzeczywisty
szum, a etykiety mogą mieć błędy. Kopia dziedziczy te ograniczenia.

- Zmiana czasu: interpolacja sygnału i przeniesienie etykiet metodą najbliższej
  próbki po tych samych współrzędnych. Marginesy `IGNORE` także się rozciągają.
- Szum, dryf i modelowe osłabienie echa: etykiety pozostają takie same.
  Krótkie dodatkowe oscylacje od szumu nie są nowymi oddechami.
- Syntetyczne oddechy od zera: etykiety wynikają z generatora, przed modelem
  IQ. Te same 60 przebiegów pozostaje wyłącznie w v1 — v2 ich nie powiela.
  Nie dodawano drugi raz modelu radaru do tych samych syntetycznych sygnałów.

## Co wygenerowano

Z roboczej części treningowej wcześniejszych źródeł:

| Źródło | Liczba kopii | Minuty odziedziczonych etykiet |
|---|---:|---:|
| Własny A121 | 117 (13 źródeł × 9) | 133,9 |
| Pas oddechowy | 96 (16 źródeł × 6) | 398,2 |
| Generator A121 od zera | 0 nowych w v2 | 300,0 pozostaje wyłącznie w v1 |

W każdej serii sześciu kopii: długość ×0,7 / 0,8 / 0,9 / 1,1 / 1,25 / 1,4;
podstawowy szum z prawdziwych pauz o odchyleniu 3–30% zakresu p5–p95;
dodatkowy składnik z wolnozmienną obwiednią ×0,5–1,5, wygładzoną na skali
3 s; losowy dryf z limitem 0,05 / 0,1 / 0,2 / 0,3 / 0,45 / 0,6 zakresu
na minutę. Dodatkowy składnik ma połowę podstawowego poziomu przed modulacją.

Dla A121 ponadto trzy przebiegi przez model IQ z osłabieniem mocy echa
0 / 6 / 12 dB przy stałym poziomie szumu odbiornika, SNR 35 / 29 / 23 dB,
clutter 0,08 i fading 0,15. Przesunięcie klatki nie jest zmniejszane. Model
przyjmuje rzeczywisty przebieg już zawierający własne zakłócenia i jest
przybliżeniem warunków pomiaru. Echo modelowe ma względne jednostki dB.
Nie stosowano tej operacji do pasa: jego jednostki nie są milimetrami.

Bank szumu: 3,0 min pauz wyłącznie z roboczego treningu A121. Wspólne metody:
`enhanced_augment_run` i `reduced_power_run` w
`src/respi_net/artificial_runs.py`. Korzysta z nich także builder bliskiego
radaru, więc oba procesy nie mają osobnych implementacji tych dodatków.

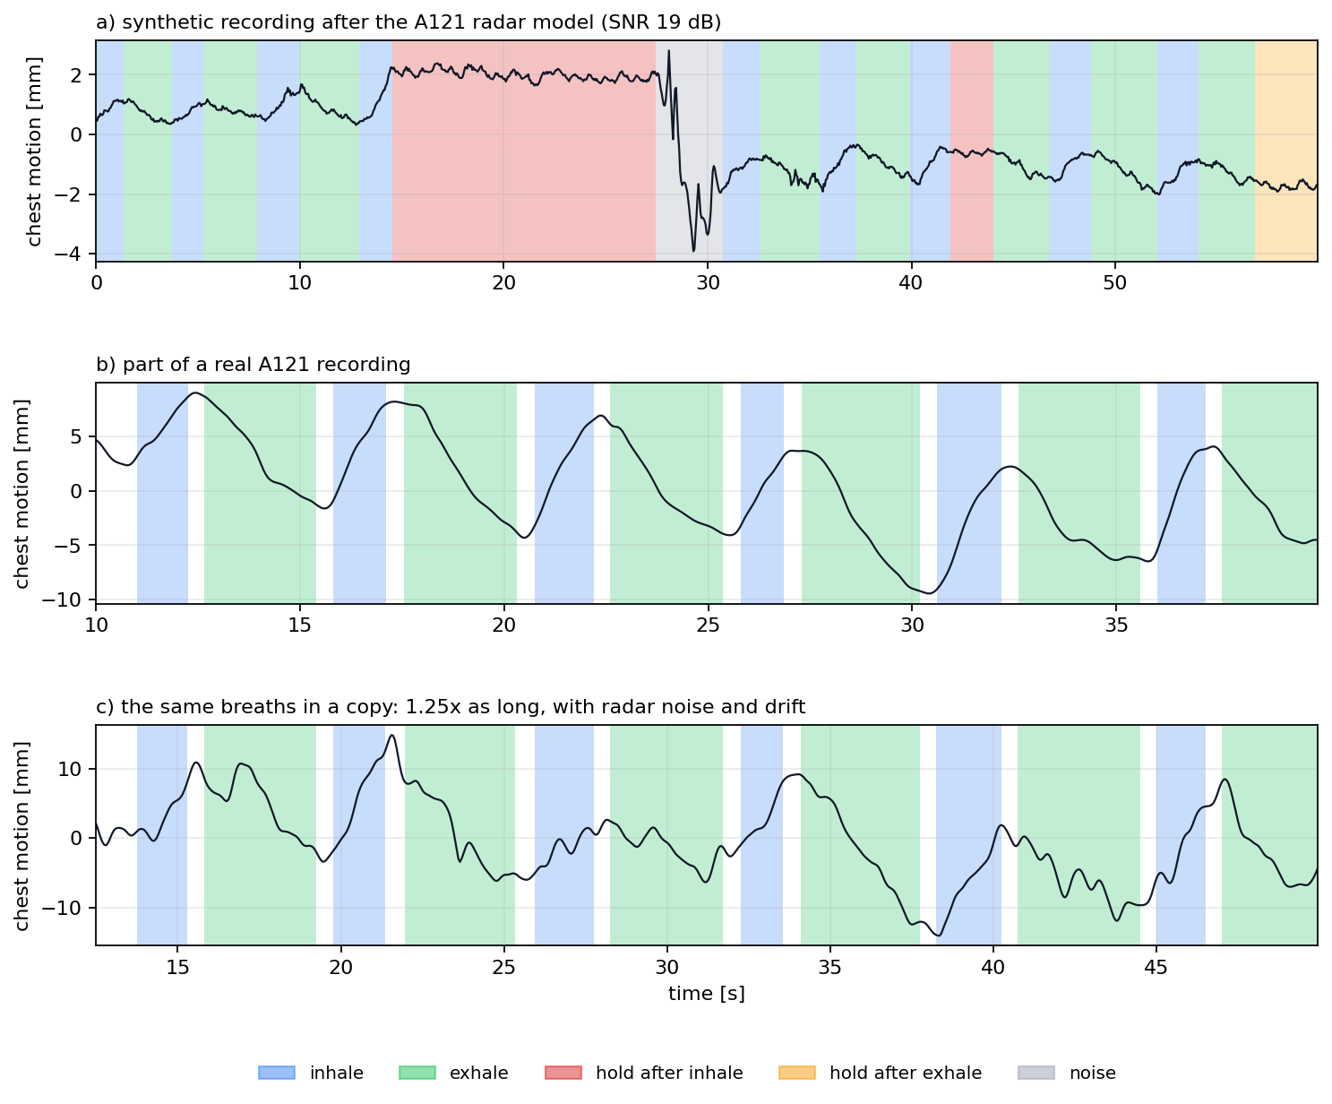
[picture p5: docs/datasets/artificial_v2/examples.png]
Źródło i kopia z odziedziczonymi oznaczeniami


## Pliki

Pełne pliki lokalne, zgodnie z dotychczasową polityką ignorowania danych
pochodnych w Git:

```text
data/processed/breath_phases/enhanced_v2/
  dataset_finetune_v2.npz    # tylko nowe rozszerzone kopie własnego radaru
  dataset_pretrain_v2.npz    # tylko nowe rozszerzone kopie pasa
  dataset_finetune_v1_plus_v2.npz  # v1 + dodatki, kontrola duplikatów
  dataset_pretrain_v1_plus_v2.npz  # v1 + dodatki, kontrola duplikatów
  artificial_summary.json
  copies/*.npz             # 213 kopii z etykietami, metadanymi i grupą źródła
```

W Git zapisano [podsumowanie](summary.json), wykres i `samples/`: jedno własne
źródło radaru oraz jego kopie ×0,7, ×1,4 i z osłabieniem echa 12 dB.
Zmodyfikowane dane pasa pozostają lokalne (CC BY-NC-ND).

Odtworzenie po przygotowaniu lokalnych źródeł jak dla v1:

```sh
uv run --offline python tools/build_artificial_data.py --enhanced \
  --summary-path docs/datasets/artificial_v2/summary.json \
  --notes-figure docs/datasets/artificial_v2/examples.png \
  --own-examples-dir docs/datasets/artificial_v2/samples
```

Seed główny: 0. Rozszerzone kopie używają niezależnych seedów 20261006
(A121) i 20261007 (pas); generator od zera zachowuje strumień losowy v1.
Okna mają 60 s, krok 10 s i 20 s kontekstu bez celów uczenia.

## V1 i v2: suma, a nie zamiana

Wcześniejszy eksport v2 zawierał całą bazę i te same 60 przebiegów
syntetycznych co v1. Poprawiono builder: v2 zapisuje teraz wyłącznie 213
nowych kopii. Dotychczasowe bazowe nagrania, sześć starszych wariantów
augmentacji i generator pozostają w v1. Nowe kopie mają końcówkę
`__enhanced_v2`, więc podobne współczynniki tempa nie powodują kolizji nazw.
Ich szum i dryf są inne, zatem nie są identycznymi kopiami starej augmentacji.

Do wykorzystania obu metod służą pliki `*_v1_plus_v2.npz`. Builder porównuje
zawartość każdego okna (sygnał i etykiety) i zapisuje identyczne okna tylko
raz. Konflikt podziału dla tej samej grupy źródłowej albo identycznych okien
powoduje błąd. Same dodatki v2 mają wyłącznie roboczy przydział train;
val/test pochodzą z v1 w pliku połączonym. Końcowy podział nadal wymaga
ponownego ustalenia po zebraniu danych.

Do uczenia wybierz połączony plik albo zestaw v1 i dodatków v2. Nie dodawaj
v1 ani v2 ponownie obok pliku połączonego. W aktualnym eksporcie dodatki mają
455 okien A121 i 1861 okien pasa; suma daje odpowiednio 806/12/12 oraz
5522/72/58 okien w roboczym train/val/test. Kontrola zawartości potwierdziła
brak identycznych okien między zachowanymi v1 a nowymi dodatkami.

Wyświetlane wyżej źródło i przebieg od zera służą porównaniu na wykresie;
nie są dodatkowo dołączane do eksportu v2. W `samples/source.npz` pozostaje
mały przykład bazowy do inspekcji, a nie kolejny zbiór treningowy.

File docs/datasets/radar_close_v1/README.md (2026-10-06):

# Ręcznie wybrane etykiety bliskich nagrań radaru — v1

Przygotowano 2026-10-06. Etykiety wyznaczono po wizualnej ocenie przebiegów
radaru; propozycje zwrotów z filtra 0,7 Hz służyły jako pomoc i zostały
przejrzane. Oznaczający: `codex_visual_review`, nie człowiek ani niezależny
pomiar fizjologiczny. Nie wykorzystano etykiet IMU. Są to **wstępne etykiety
sygnału**, do dalszego przeglądu i docelowo sprawdzenia z pasem.

## Zawartość

Edytowalne przedziały: `annotations/radar_close_v1/*.json`. Klasy: 0 wydech,
1 pauza po wydechu, 2 wdech, 3 pauza po wdechu, 4 szum; −1 pominięte.
Początek przedziału jest włączony, koniec wyłączony, czas liczony od początku
pomiaru. Poza zaznaczonymi przedziałami wszystko pozostaje bez etykiety.

| Nagranie | Podział | Oznaczony czas po maskowaniu | Uwagi |
|---|---|---:|---|
| `phase1_halfside_02` | train | 125,10 s | Czytelne cykle i dwie celowe pauzy po wdechu; pominięty słabszy fragment 35,64–67,49 s. |
| `pilot_coach_1m` | train | 73,40 s | Czytelne cykle i długa pauza po wydechu; komendy wspierają interpretację pauzy. |
| `self_lying_3min_01` | val | 66,00 s | Wybrane oddechy; pozorne plateau pominięte, bo notatki mówią o braku celowych pauz. |
| `sit_nophone_01` | test | 54,75 s | Telefon poza ciałem i wiązką; rodzaje pauz wspierają komendy; widoczny dryf pozostaje ograniczeniem. |

Razem **319,25 s (5,32 min)**. W czytelnym sygnale nie ma automatycznych
przerw przy wdech–wydech: etykieta zmienia się bezpośrednio na granicy.
Tylko wskazane w przeglądzie szersze/nierówne szczyty mają lokalnie
±0,2–0,3 s marginesu. Przy niejednoznacznych granicach pauz pozostawiono
±0,25–0,7 s zależnie od ostrości zwrotu i osiadania. Nie ma mocnego powodu
wycinać próbek przy każdym czystym zwrocie; korzyść z lokalnych marginesów
wymaga dopiero sprawdzenia przy uczeniu.
Każdy wyjątek zapisano w JSON jako `boundary_overrides` z czasem, marginesem
i uzasadnieniem. Wyjątek zastępuje domyślny margines po obu stronach granicy,
a nie dodaje kolejnego maskowania. Dłuższe nieoznaczone fragmenty pozostają
pominięte. Są to marginesy ostrożności, nie zmierzony błąd czasu.

Białe fragmenty nie są klasą pauzy. Nie wnoszą błędu do funkcji straty,
lecz ich sygnał nadal jest kontekstem dla sieci. Nie narzucają opóźnienia
predykcji ani tego, którą klasę sieć ma tam zwrócić. Przygotowano ponownie
wszystkie 18 kopii i okna z aktualnych etykiet źródła.

Nie oznaczono klasy szumu. To mały zbiór pilotażowy,
nie kompletny materiał do oceny modelu pięcioklasowego.

Wykresy obok tego pliku: niebieski wdech, zielony wydech, czerwony pauza po
wdechu, żółty pauza po wydechu, białe pominięte. Szary przebieg: fazowe
przesunięcie przed filtrem LP, po odjęciu trendu liniowego; czarny: LP 2 Hz.

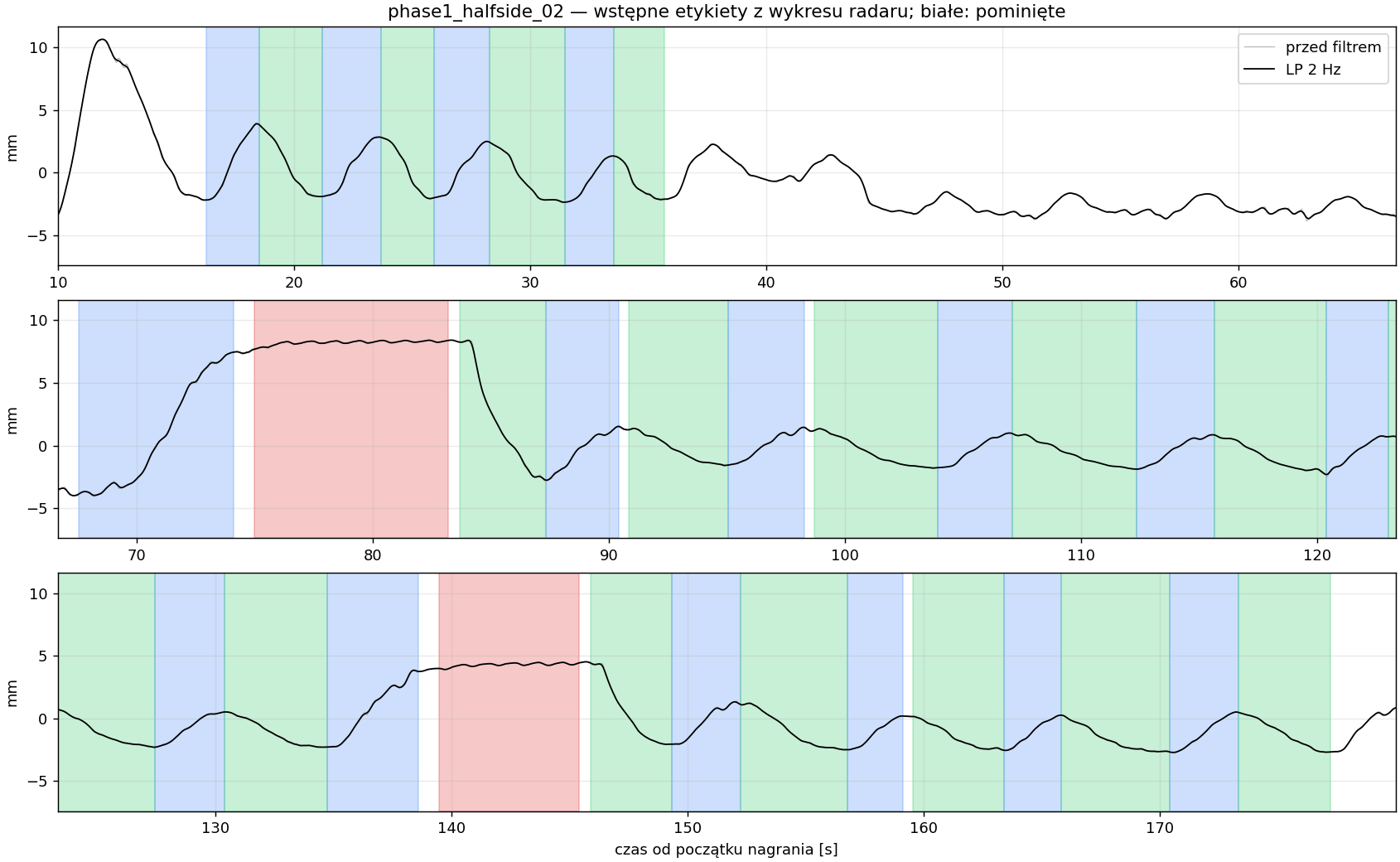
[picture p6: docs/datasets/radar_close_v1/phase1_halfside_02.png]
Etykiety najlepszego nagrania


## Próbki sztuczne i wcześniejszy proces

Wcześniejszy `tools/build_artificial_data.py` tworzy sześć kopii nagrania
treningowego z długością ×0,7 / 0,8 / 0,9 / 1,1 / 1,25 / 1,4. Sygnał jest
interpolowany, etykiety przenoszone po tych samych współrzędnych. Dodaje szum
z prawdziwych pauz radaru, o odchyleniu 3–30% zakresu p5–p95 sygnału, i wolny
dryf losowy, maksymalnie 0,3 tego zakresu na minutę. Bank szumu pochodzi
wyłącznie z treningu. Osobno generuje od zera oddechy, pauzy, westchnienia,
tętno i ruch, a następnie modeluje A121: fazę IQ, clutter, fading i szum.

Nowa paczka wykorzystuje istniejące `augment_run`, `noise_bank_from_holds`,
`a121_forward` i `displacement_from_iq`; nowe rozszerzenia są współdzielone przez oba buildery.
Z dwóch nagrań treningowych powstało **18 kopii**, z 30,27 min odziedziczonych
etykiet po maskowaniu (to nie jest 30,27 min nowych pomiarów):

- 12 kopii ze starymi współczynnikami czasu i zakresem szumu, z dryfem
  zmienionym między kopiami: 0,05 / 0,1 / 0,2 / 0,3 / 0,45 / 0,6 zakresu
  p5–p95 na minutę. Dryf zmienia kierunek i nachylenie w czasie, jak wcześniej.
- Nowość: dodatkowy składnik prawdziwego szumu z pauz, z wolnozmienną obwiednią
  ×0,5–1,5, wygładzoną na skali 3 s. Podane 3–30% opisuje podstawowy składnik;
  dodatkowy składnik ma połowę tego poziomu przed modulacją. To warianty
  obciążające metodę, a nie nowe potwierdzone warunki pomiaru.
- 6 kopii istniejących przebiegów przez model IQ: obniżenie mocy echa o
  0 / 6 / 12 dB przy stałym szumie odbiornika, SNR 35 / 29 / 23 dB, clutter
  0,08 i fading 0,15. Mniejsza moc echa nie jest mniejszym ruchem klatki.
  Kanał echo tych kopii jest względny i modelowy, nie skalibrowany jak realny.
  Źródłowy przebieg ma już własny szum i dryf; model jest przybliżeniem.

Nie generowano kolejnej paczki oddechów od zera. Wszystkie nowe kopie mają
pochodzenie w konkretnym nagraniu. Etykiety i ich niepewność przechodzą do
kopii; augmentacja nie potwierdza poprawności oznaczeń.

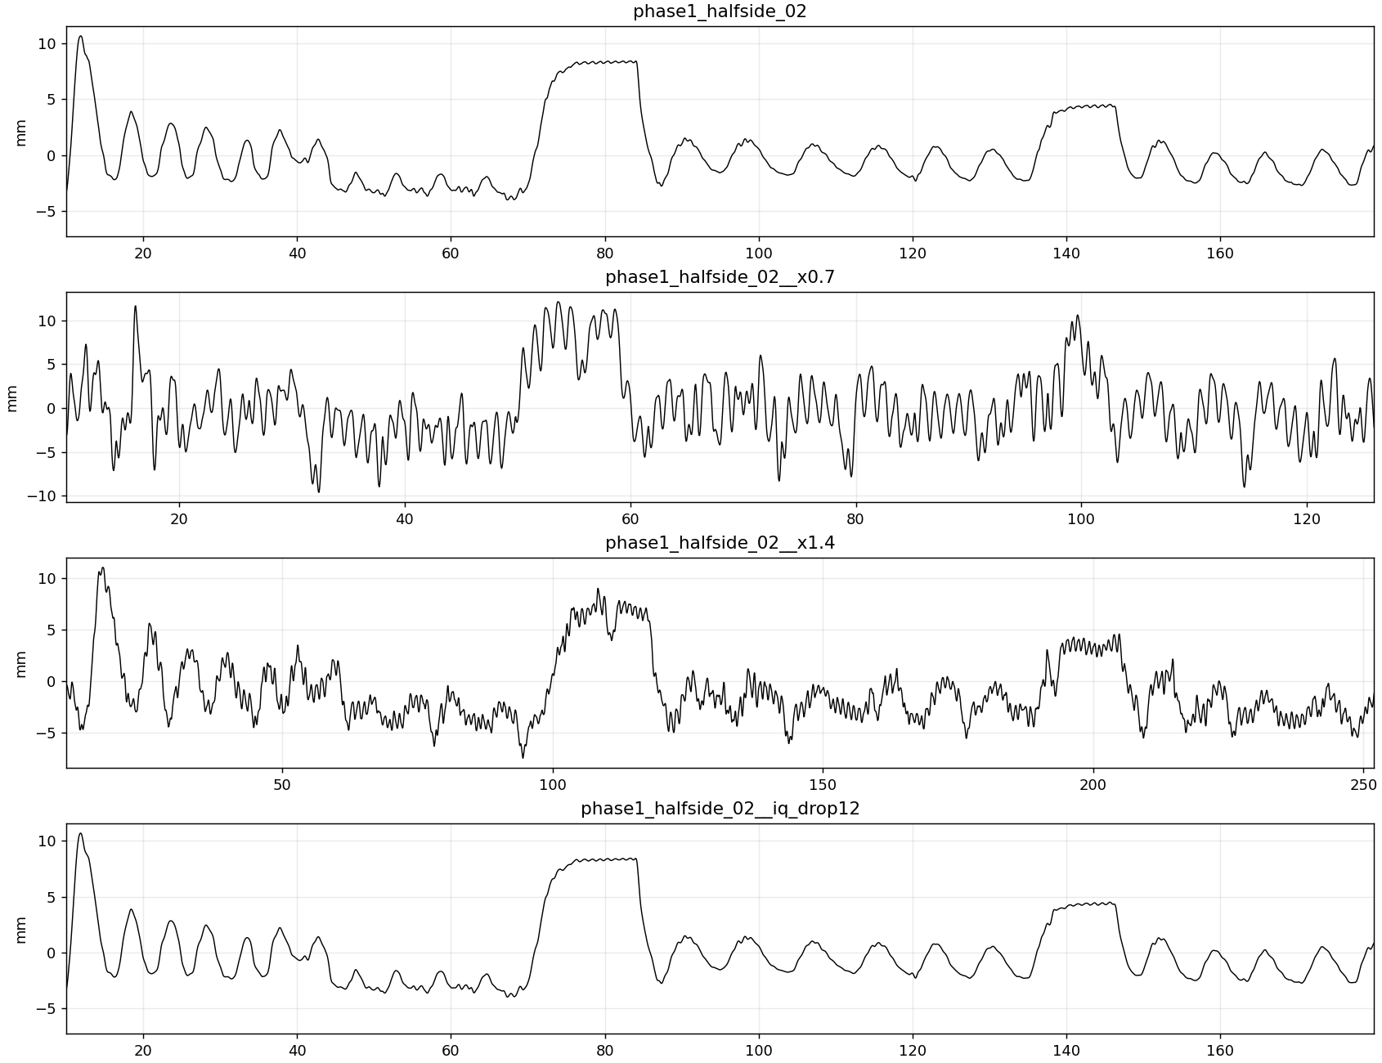
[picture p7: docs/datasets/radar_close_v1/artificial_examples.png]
Przykłady augmentacji


## Zapis, odtwarzanie i wykorzystanie

### Status podziału: roboczy, do ustalenia po zebraniu danych

Obecne nazwy train/val/test są wyłącznie technicznym przydziałem potrzebnym
do eksportu i kontroli pochodzenia kopii. Większość planowanych danych jeszcze
nie istnieje. Nie traktujemy więc obecnych nagrań val/test jako zamrożonego
zbioru do wyboru modelu, strojenia ani raportowania końcowych wyników.
Po zakończeniu zbierania trzeba zaplanować podział po niezależnych sesjach
(w razie potrzeby po osobach), ustalić bank szumu z nowego treningu i ponownie
wygenerować kopie oraz okna. Przeniesienie tylko oryginału do testu przy
pozostawieniu jego kopii lub szumu w treningu powodowałoby przeciek.

W bieżącej wersji zachowujemy przydziały, żeby paczka pozostawała odtwarzalna;
nie jest to twierdzenie, że obecny podział ma wartość końcowej walidacji.

`annotations/radar_close_v1/sources/` zawiera niewielkie NPZ z czasem,
przesunięciem przed/po filtrze i echem oraz SHA256 źródłowego CSV. Dzięki temu
paczka działa też bez dużych lokalnych plików IQ. Jeśli surowy plik jest
dostępny, jego hash musi zgadzać się ze snapshotem. Pełny IQ pozostaje
ignorowany przez Git zgodnie z istniejącą polityką repo.

`annotations/radar_close_v1/generated/` zawiera 4 rzeczywiste przebiegi,
18 kopii, podsumowanie i `dataset_manual_radar_v1.npz` w istniejącym formacie
sieci: 60 s okna, krok 10 s, pierwsze 20 s jako kontekst bez celów uczenia,
normalizacja przyczynowa z poprzednich 30 s. Okna nakładają się, więc ich
liczba nie jest liczbą niezależnych prób: **158 train, 6 val, 2 test**.

Każda kopia zachowuje grupę źródła. Walidacja i test zawierają tylko prawdziwe
przebiegi i nie dostarczają szumu treningowego. Podział jest po nagraniach,
nie po osobach (wszystko od jednej osoby), i nie dowodzi generalizacji.
Ocena na tych etykietach będzie oceną zgodności z interpretacją wykresu;
potwierdzenie faz fizjologicznych wymaga niezależnego odniesienia. W val brak
pauz, a w całym zbiorze brak klasy szumu — potrzebne są dalsze nagrania.

Odtworzenie:

```sh
uv run --offline python tools/build_manual_radar_data.py
uv run --offline pytest -q tests/test_manual_radar_data.py tests/test_artificial_runs.py tests/test_breath_synth.py tests/test_breath_phase_dataset.py
```

Seed: 20261006. Nie wykonano treningu sieci. Nowe warianty zostały też zastosowane do wcześniejszych źródeł w osobnej
paczce [artificial_v2](../artificial_v2/README.md). Wspólne funkcje znajdują się
w `src/respi_net/artificial_runs.py`; wcześniejsze eksporty v1 są zachowane.

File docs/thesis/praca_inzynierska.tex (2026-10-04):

% =====================================================================
%  PRACA INŻYNIERSKA — SZKIC ROBOCZY (jeden plik)
%  "Sieci neuronowe do analizy rytmu oddechowego"
%  Maciej Łukasiewicz (197865) — Politechnika Gdańska
%  Promotor: dr hab. inż. Julian Szymański
%
%  Kompilacja:  tectonic praca_inzynierska.tex
%           lub  latexmk -pdf praca_inzynierska.tex
%
%  UWAGA: [TODO: ...] oznacza miejsca do uzupełnienia — usunąć makro
%  \todo przed oddaniem pracy.
% =====================================================================
\documentclass[12pt,a4paper,oneside]{report}

% Obsługa czcionek: działa zarówno pod XeLaTeX/tectonic, jak i pdfLaTeX
% (np. na Overleafie). Bez tego znaki diakrytyczne znikają z PDF-a.
\usepackage{iftex}
\ifPDFTeX
  \usepackage[utf8]{inputenc}
  \usepackage[T1]{fontenc}
  \usepackage{lmodern}
\else
  \usepackage{fontspec}
  \setmainfont{lmroman10-regular.otf}[
    BoldFont       = lmroman10-bold.otf,
    ItalicFont     = lmroman10-italic.otf,
    BoldItalicFont = lmroman10-bolditalic.otf]
  \setsansfont{lmsans10-regular.otf}[
    BoldFont   = lmsans10-bold.otf,
    ItalicFont = lmsans10-oblique.otf]
  \setmonofont{lmmono10-regular.otf}[
    BoldFont   = lmmonolt10-bold.otf,
    ItalicFont = lmmono10-italic.otf]
\fi
\usepackage[polish]{babel}
\usepackage[margin=2.5cm,bindingoffset=0.5cm]{geometry}
\usepackage{setspace}
\onehalfspacing

\usepackage{graphicx}
\graphicspath{{figures/}}
\usepackage{float}
\usepackage{subcaption}
\usepackage{booktabs}
\usepackage{longtable}
\usepackage{amsmath}
\usepackage{siunitx}
\sisetup{output-decimal-marker={,}}
\usepackage{xcolor}
\usepackage{tikz}
\setlength{\emergencystretch}{3em}  % ostatnia deska ratunku dla łamania akapitów
\usetikzlibrary{arrows.meta,positioning,fit,backgrounds}
\usepackage[hidelinks]{hyperref}

% Styl schematów blokowych potoku przetwarzania.
\tikzset{
  blok/.style   = {draw, rounded corners=2pt, align=center, font=\small,
                   minimum height=8mm, inner sep=4pt, fill=blue!5, draw=blue!45},
  wejscie/.style= {draw, rounded corners=2pt, align=center, font=\small,
                   minimum height=8mm, inner sep=4pt, fill=gray!10, draw=gray!55},
  wynik/.style  = {draw, rounded corners=2pt, align=center, font=\small,
                   minimum height=8mm, inner sep=4pt, fill=green!8, draw=green!45!black},
  strzalka/.style = {-{Latex[length=2mm]}, draw=gray!70},
}

% Znacznik miejsc do uzupełnienia (usunąć w wersji finalnej).
\newcommand{\todo}[1]{\textcolor{red!75!black}{\textbf{[TODO: #1]}}}
% Starsza nazwa zachowana dla istniejących odwołań; wszystkie rezerwy są
% celowo widoczne w PDF jako czerwone TODO.
\newcommand{\miejsce}[1]{\todo{#1}}

% Numery rysunków dwucyfrowych (np. 12.10) potrzebują szerszej kolumny
% w~spisie rysunków, aby podpis nie stykał się z~numerem.
\makeatletter
\renewcommand*\l@figure{\@dottedtocline{1}{1.5em}{3.0em}}
\makeatother

\title{Sieci neuronowe do analizy rytmu oddechowego}
\author{Maciej Łukasiewicz}
\date{Gdańsk 2026}

\begin{document}

% =====================================================================
% STRONA TYTUŁOWA
% =====================================================================
\begin{titlepage}
    \centering
    {\large Politechnika Gdańska\\[0.2em]
    Wydział Elektroniki, Telekomunikacji i Informatyki\par}
    \vspace{3.5cm}

    {\large Praca dyplomowa inżynierska\par}
    \vspace{1.2cm}
    {\LARGE\bfseries Sieci neuronowe do analizy\\[0.3em] rytmu oddechowego\par}
    \vspace{0.8cm}
    {\large\itshape Neural networks for respiratory rhythm analysis\par}
    \vspace{3cm}

    {\large Autor: Maciej Łukasiewicz (197865)\par}
    \vspace{0.4cm}
    {\large Promotor: dr hab. inż. Julian Szymański\par}
    \vfill
    {\large Gdańsk 2026\par}
    \vspace{0.5cm}
    {\footnotesize\todo{Zastąpić stronę tytułową wzorem z~MojaPG.}\par}
\end{titlepage}

% =====================================================================
% STRESZCZENIA
% =====================================================================
\chapter*{Streszczenie}
\addcontentsline{toc}{chapter}{Streszczenie}

Praca dotyczy bezkontaktowego pomiaru rytmu oddechowego i tętna przy użyciu
radaru. W ramach części implementacyjnej zbudowano dwa niezależne tory
pomiarowe: niskokosztowy radar dopplerowski HB100 (\SI{10.525}{GHz}) wraz
z zaprojektowanym od podstaw analogowym układem kondycjonowania sygnału oraz
radar impulsowo-koherentny Acconeer A121 (\SI{60}{GHz}) pracujący na surowych
danych Sparse~IQ. Opracowano algorytmy estymacji częstości oddechu i tętna
oparte na analizie fazy sygnału odbitego, aplikację desktopową do akwizycji
i podglądu na żywo oraz zestaw narzędzi do analizy offline. Przeprowadzono
równoczesne porównanie obu radarów: HB100 wykrywał obecność sterowanego
oddechu i~jego zatrzymanie w~powtarzanej serii do \SI{100}{cm} oraz
w~pojedynczym reteście \SI{150}{cm}. Dla pełnych, pogłębionych oddechów
estymator konsensusu harmonicznych HB100 w~12 blokach powtarzanej serii
\SIrange{30}{100}{cm} odtworzył zadany rytm \SI{0.20}{Hz} w~zakresie
\SIrange{0.198}{0.204}{Hz}. W~pojedynczym reteście \SI{150}{cm} uzyskano
\SI{0.190}{Hz} i~\SI{0.202}{Hz}, lecz z~małym marginesem jakości, dlatego
wynik traktowano jedynie jako wskazanie rytmu. Jednokanałowy przebieg nie
zachowywał stabilnie kierunku wdech--wydech; A121 umożliwiał taką analizę na
podstawie fazy I/Q. Przeprowadzono również
kontrolowany eksperyment porównujący trzy soczewki dielektryczne
(hiperboliczną, FZP i płaską pokrywę) oraz wpływ folii aluminiowej naklejonej
na klatkę piersiową (36 nagrań). W części eksperymentalnej system zastosowano
do całonocnego monitoringu snu, porównując wyniki z zegarkiem Garmin~Fenix~7.

\todo{Uzupełnić streszczenie o wyniki końcowe sieci neuronowych, gdy powstaną.}

\paragraph{Słowa kluczowe:} radar dopplerowski, radar impulsowo-koherentny,
rytm oddechowy, parametry witalne, HB100, Acconeer A121, analiza snu, sieci
neuronowe.

\clearpage
\chapter*{Abstract}
\addcontentsline{toc}{chapter}{Abstract}

\todo{Dodać streszczenie w~języku angielskim.}

\clearpage

% =====================================================================
\tableofcontents
\listoffigures
\listoftables

% =====================================================================
% WSTĘP
% =====================================================================
\chapter{Wstęp}

\section{Motywacja}
Rytm oddechowy i tętno należą do podstawowych parametrów opisujących stan
fizjologiczny człowieka. Ich długotrwała obserwacja jest istotna między innymi
w~medycynie snu, opiece domowej i~monitorowaniu osób, dla których zakładanie
klasycznych czujników może być uciążliwe. Pasy oddechowe, elektrody EKG
i~pulsoksymetry zapewniają bezpośredniejszy związek z~mierzoną wielkością, ale
wymagają kontaktu z~ciałem, właściwego założenia i~tolerowania przewodów lub
urządzenia nasobnego przez całą noc.

W~pracy rozpatrzono dwie grupy metod mniej typowych. Pierwszą stanowią radary,
które rejestrują ruch powierzchni ciała bez kontaktu i~nie zależą od oświetlenia.
Drugą są czujniki inercyjne: osobny moduł LSM6DS3 oraz sensory wbudowane
w~telefonie. IMU nie jest w~tej pracy wzorcem dla radaru, lecz niezależnym,
kontaktowym sposobem obserwowania kinematyki klatki piersiowej. Jego zaletą jest
niski koszt i~powszechna dostępność, szczególnie gdy akwizycję realizuje zwykły
smartfon. Badanie obejmuje zatem nie tylko dokładność estymowanej częstości, ale
również praktyczną użyteczność sygnału w~różnych pozycjach ciała.
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

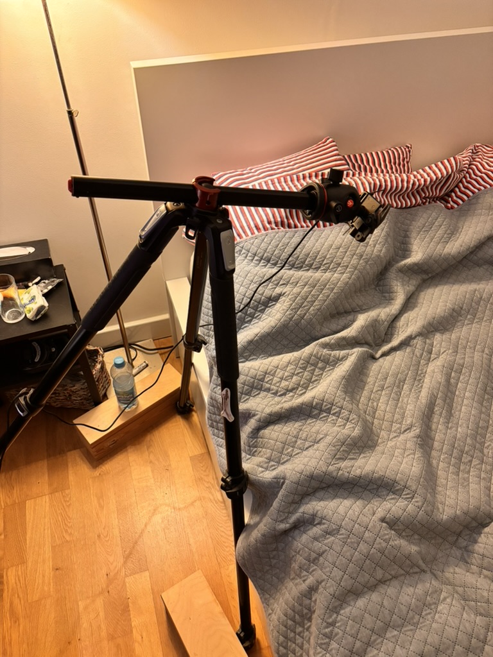
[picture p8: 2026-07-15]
docs/thesis/figures/stanowisko_a121_nad_lozkiem.jpg

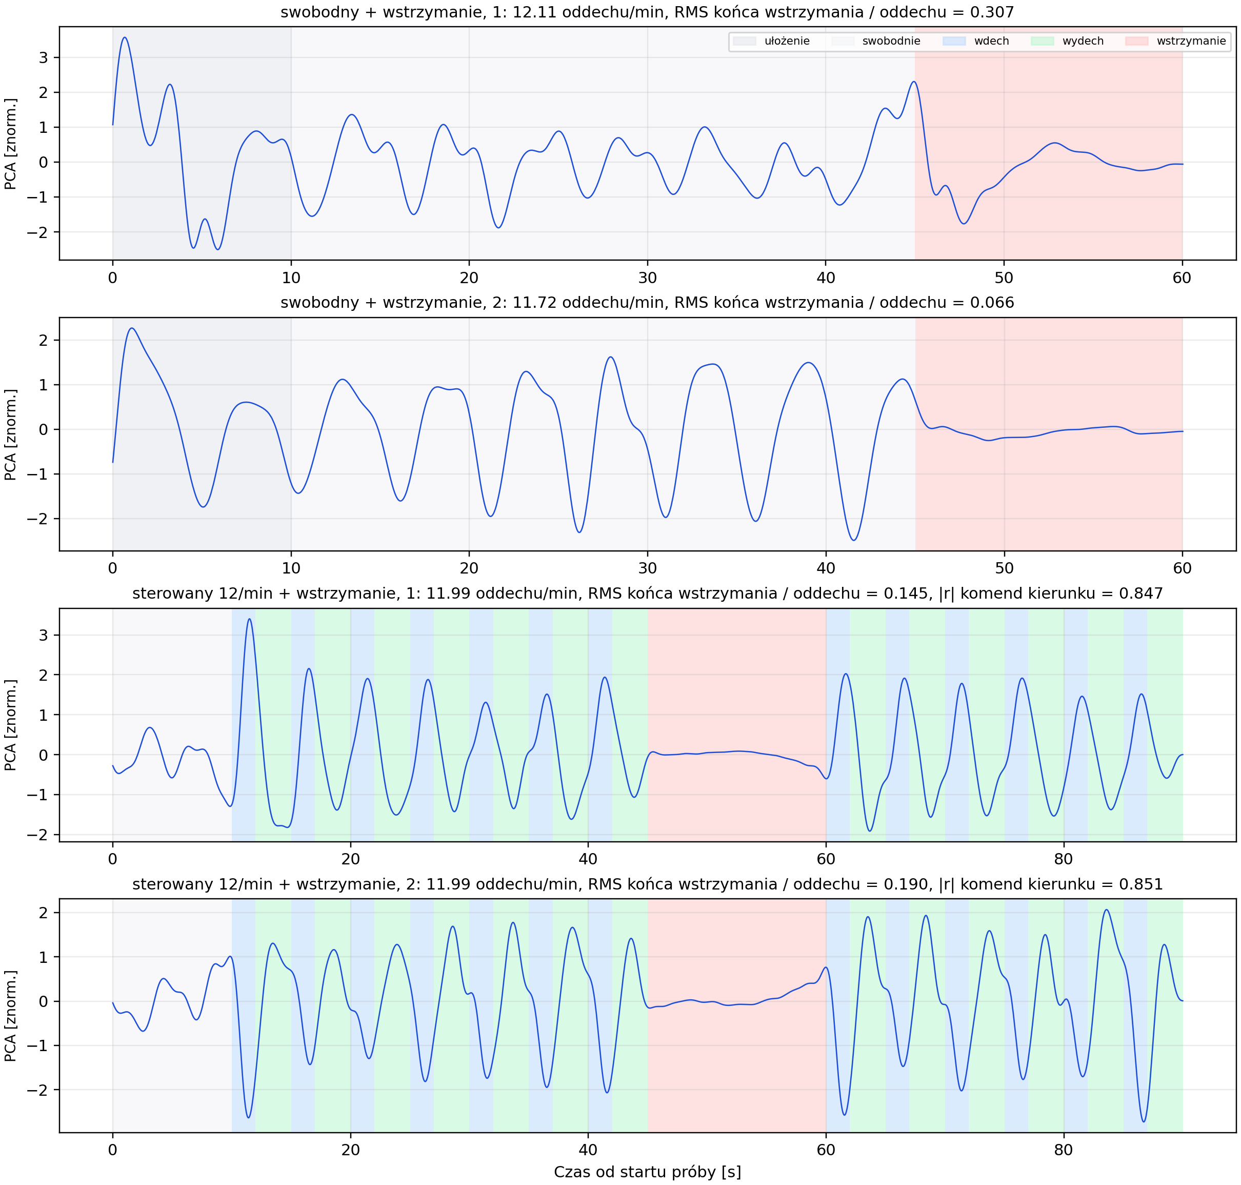
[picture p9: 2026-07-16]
docs/thesis/figures/imu_lsm6ds3_klatka_piersiowa.png

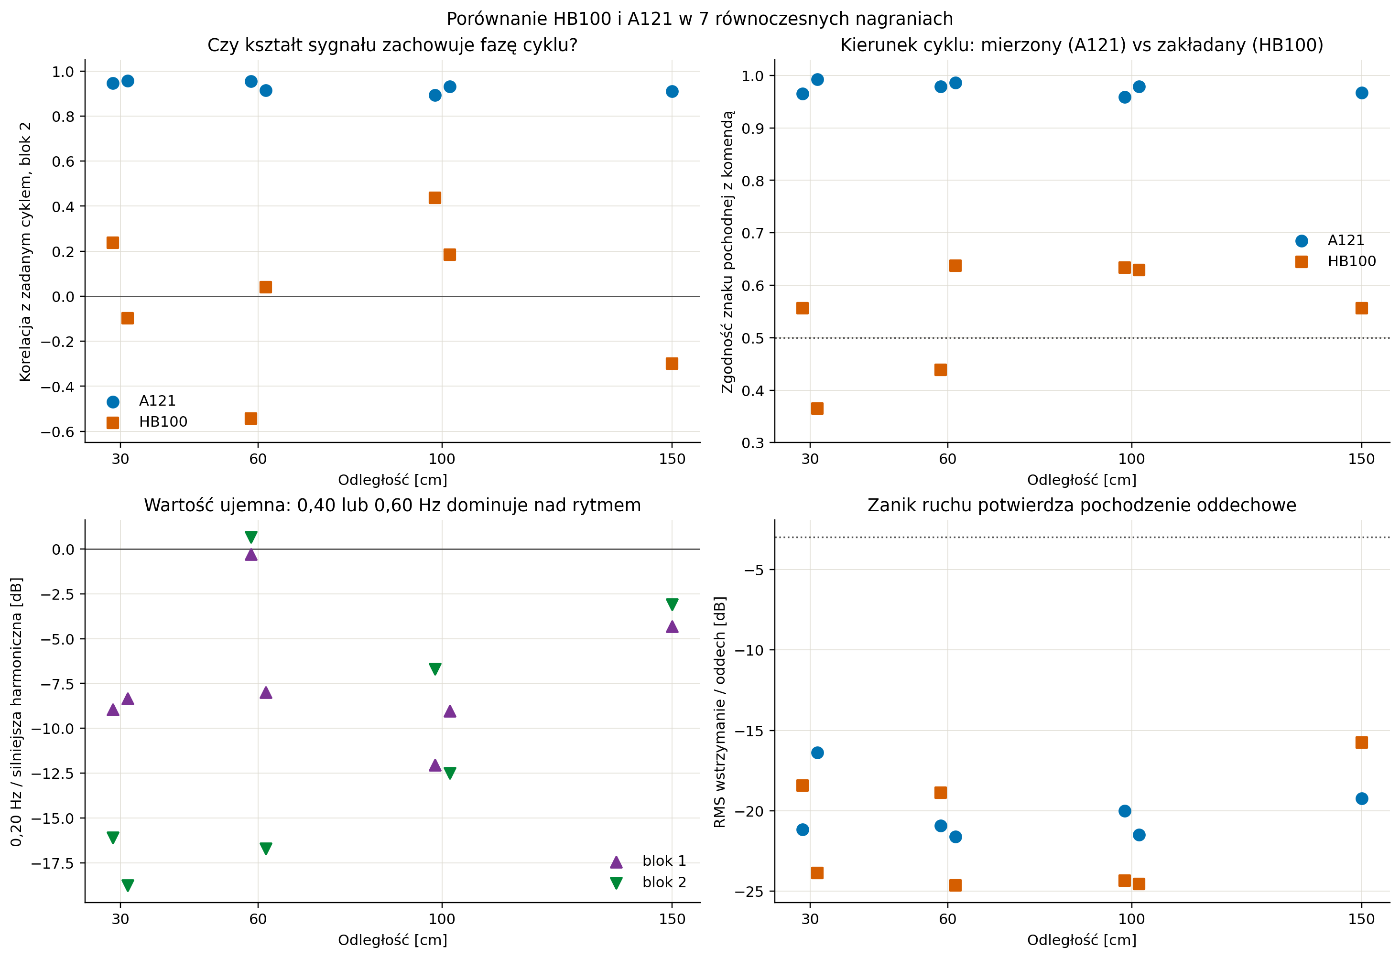
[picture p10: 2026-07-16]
docs/thesis/figures/hb100_a121_metryki.png

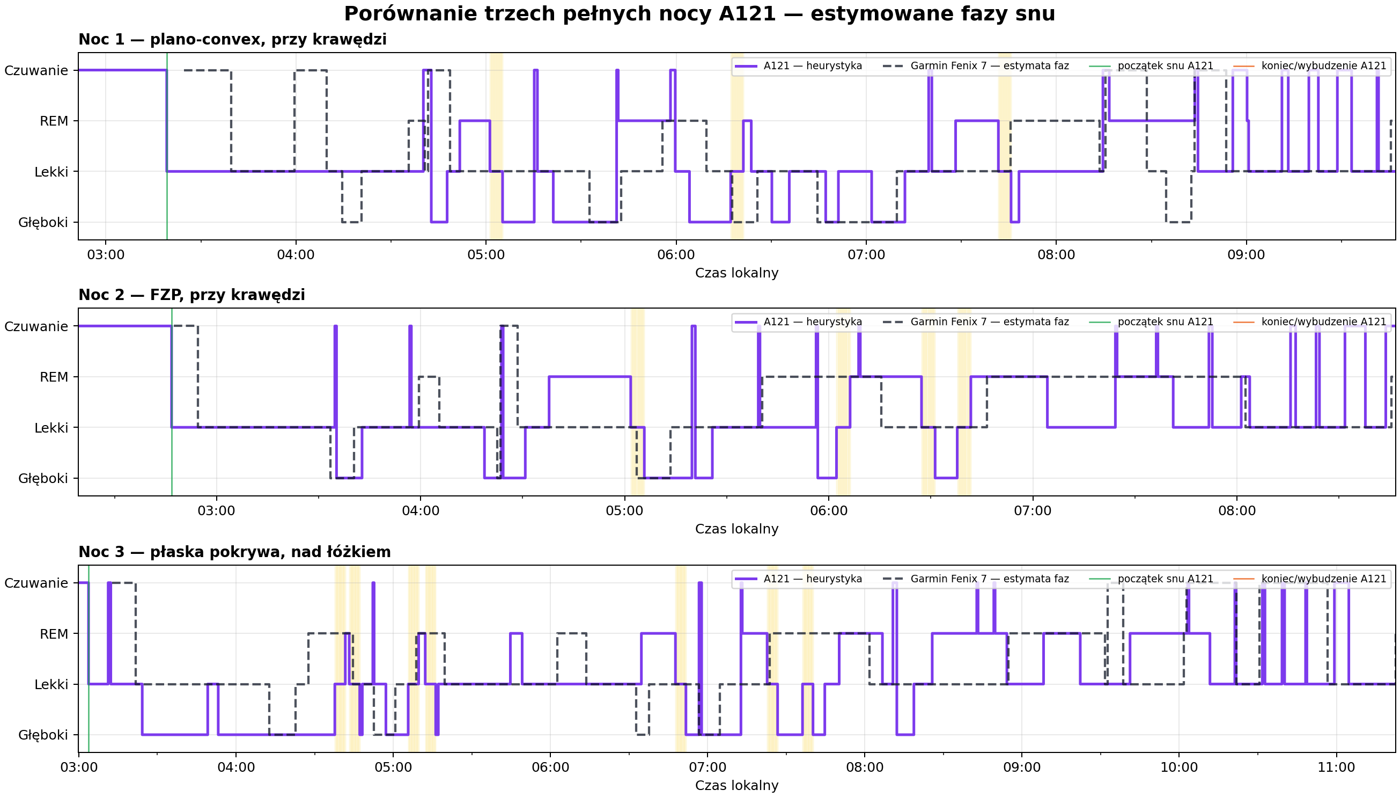
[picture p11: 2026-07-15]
docs/thesis/figures/sen_porownanie_konfiguracji_fazy.png

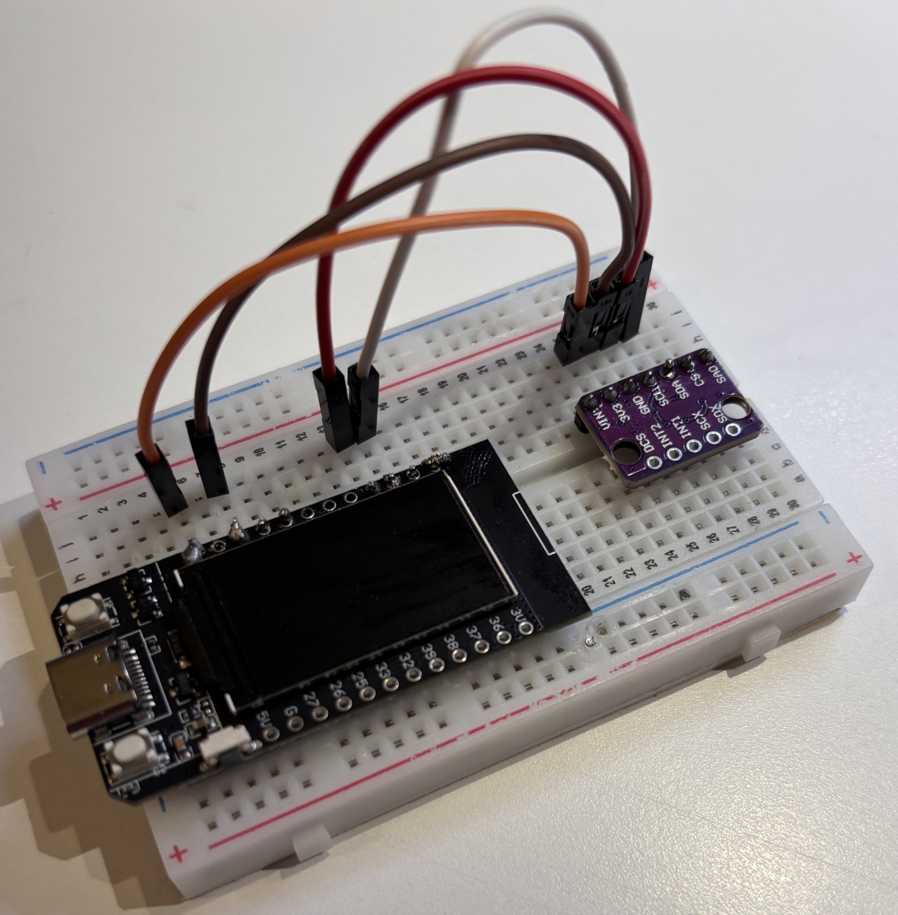
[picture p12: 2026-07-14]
docs/thesis/figures/stanowisko_lsm6ds3.jpg

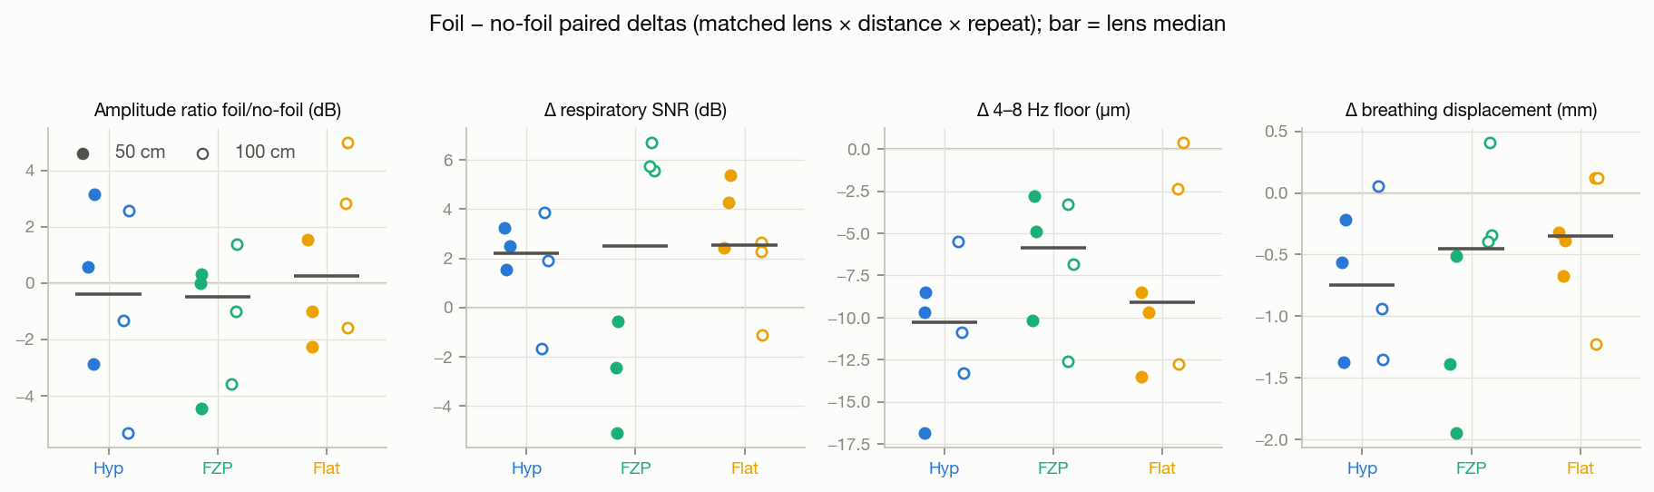
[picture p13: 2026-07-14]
docs/thesis/figures/foil_delty_parowane.png

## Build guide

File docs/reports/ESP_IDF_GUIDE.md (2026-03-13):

# ESP-IDF Environment & Build Guide

This guide documents the specific configurations and fixes needed to build and flash ESP32 projects on this system, avoiding the "Environment not set up" errors encountered during development.

## 1. Environment Paths

The primary ESP-IDF installation and tools are located here:
- **IDF_PATH**: `C:\espressif\frameworks\esp-idf-v5.5.3`
- **IDF_TOOLS_PATH**: `C:\Users\macie\.espressif` (Required for compilers, ninja, ccache)

## 2. Successful Activation (PowerShell)

Standard activation via `. .\export.ps1` may fail due to specific shell configurations or dot-sourcing issues. Use this sequence for a guaranteed setup:

```powershell
# 1. Explicitly set the tools path (Crucial for finding the compiler)
$env:IDF_TOOLS_PATH = 'C:\Users\macie\.espressif'

# 2. Navigate to the ESP-IDF root
cd C:\espressif\frameworks\esp-idf-v5.5.3

# 3. Source the export script
. .\export.ps1

# 4. Return to your project and build
cd path\to\your\project
idf.py build
```

## 3. ESP-IDF v5 ADC API Tips

If using ESP-IDF **v5.x**, the older `esp_adc_cal` component is deprecated.

### CMakeLists.txt
Use `esp_adc` instead of `esp_adc_cal`:
```cmake
idf_component_register(SRCS "main.c"
                    PRIV_REQUIRES driver esp_timer esp_adc)
```

### C Code (radar_main.c)
- Use `#include "esp_adc/adc_oneshot.h"`.
- Structs use `_cfg_t` suffix instead of `_config_t` (e.g., `adc_oneshot_unit_init_cfg_t`).
- Use `ADC_ATTEN_DB_12` instead of the deprecated `ADC_ATTEN_DB_11`.

## 4. Common Troubleshooting

| Issue | Cause | Fix |
| :--- | :--- | :--- |
| `idf.py: The term 'idf.py' is not recognized` | `export.ps1` failed or wasn't run. | Ensure the Activation sequence in Step 2 is followed exactly. |
| `ninja: error: rebuild 'build.ninja' failed` | Component dependency error or toolchain not found. | Check `IDF_TOOLS_PATH` and verify `PRIV_REQUIRES` in `CMakeLists.txt`. |
| `xtensa-esp32-elf-gcc: not found` | Compiler path missing from $env:PATH. | Running `. .\export.ps1` with `$env:IDF_TOOLS_PATH` set fixes this. |

## 5. Helpful Commands

- **List Serial Ports**: `[System.IO.Ports.SerialPort]::GetPortNames()`
- **Build & Flash**: `idf.py -p (PORT) flash monitor`
- **Clean Build**: `idf.py fullclean`

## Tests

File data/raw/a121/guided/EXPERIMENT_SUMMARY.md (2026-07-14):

# A121 aluminium-foil experiment brief

## Purpose

Test whether a **5 x 5 cm kitchen aluminium-foil patch attached to the chest with tape** improves the usable A121 respiratory signal, and whether the effect depends on the lens. The analysis should compare foil-attached and foil-removed recordings at the same lens and distance; raw amplitude alone is not sufficient because a stronger reflection can still have worse respiratory SNR.

## Hardware and acquisition

- Sensor: Acconeer A121 over WCH USB Dual_Serial Interface A.
- Lenses: Hyperbolic, FZP, and Flat Cover.
- Distances: 50 cm and 100 cm.
- A121 profile: 3.
- HWAAS: 32.
- Sweeps/frame: 8.
- Frame rate: 20 Hz.
- Requested range: 0.20–1.50 m.
- Recording duration: 60 seconds per accepted measurement, after a 10-second preparation period.
- Three repeats per condition.

## Design and data completeness

There are 12 conditions: 2 patch states x 2 distances x 3 lenses. Each has 3 repeats, for **36 accepted CSV recordings**:

1. Runs 1–18: foil patch attached with tape.
2. Runs 19–36: foil patch removed.

The recordings are stored under `data/raw/a121/guided/`:

- `guided_2026-07-13_23-45-25/`: run 1, created with the earlier filename/manifest format.
- `guided_2026-07-13_23-53-27/`: runs 2–18.
- `guided_2026-07-14_17-58-54/`: runs 19–36.
- `guided_2026-07-13_23-39-59/`: empty smoke-test session; ignore it.

Each recording contains approximately 1,200 frames. The current manifests mark all 36 measurements as accepted. Run 1 maps to condition 1, repeat 1: foil attached, 50 cm, Hyperbolic lens.

## Suggested analysis

Match recordings by `(distance, lens, repeat)` and compare foil-attached versus foil-removed values. Useful primary measures are respiratory-band SNR or PSD peak prominence in approximately 0.10–0.50 Hz, respiration-rate confidence, signal-quality score, target-distance stability, and valid/presence-frame percentage. Report peak amplitude as a secondary measure.

The order was not randomized: all foil-attached measurements were recorded before all foil-removed measurements. Therefore, lens/distance comparisons are useful, but foil effects should be reported with the possible influence of time, posture, sensor alignment, and subject drift explicitly acknowledged.

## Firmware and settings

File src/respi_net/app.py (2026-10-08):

from __future__ import annotations

import csv
import json
import sqlite3
import sys
import time
from datetime import datetime
from pathlib import Path
from typing import Any

import numpy as np
import pandas as pd
import pyqtgraph as pg
from PySide6 import QtCore, QtGui, QtWidgets
from scipy.signal import find_peaks, welch

from .a121 import A121_CAPTURE_COLUMNS, A121_COLUMNS, A121Config, A121Capture, parse_json_array
from .a121_breaths import default_breath_annotations_path, generate_a121_breath_annotations
from .chest_signal import A121_CHEST_SIGN, PHASE_TO_MM, a121_chest_signal
from .a121_vitals import (
    A121_RATE_WINDOW_S,
    A121_RESP_BAND_HZ,
    HEART_BAND_HZ,
    RESP_BAND_HZ,
    RESP_RATE_CONFIDENCE_MIN,
    A121LiveTraceProcessor,
    HeartRateKalmanTracker,
    analyze_a121_vitals,
    bandpass_filter,
    clean_signal,
)
from .imu import DEFAULT_IMU_BAUD, IMU_COLUMNS, LSM6DS3_CAPTURE_COLUMNS, BreathCapture
from .iphone_imu import IPhoneIMUBluetoothCapture
from .paths import (
    DATA_DIR,
    PROJECT_ROOT,
    RAW_A121_DIR,
    RAW_IMU_DIR,
    RAW_RADAR_DIR,
    resolve_recordings_db_path,
)
from .radar import DEFAULT_RADAR_BAUD, DOPPLER_HZ_PER_MPS, RADAR_COLUMNS, RadarCapture
from .serial_utils import list_serial_ports

DB_PATH = resolve_recordings_db_path()


class RecordingStore:
    """Small SQLite store for live sessions and their raw samples."""

    def __init__(self, path: str | Path | None = None):
        self.path = Path(path) if path is not None else resolve_recordings_db_path()
        self.path.parent.mkdir(parents=True, exist_ok=True)
        self._init_schema()

    def _connect(self) -> sqlite3.Connection:
        return sqlite3.connect(self.path)

    def _init_schema(self) -> None:
        with self._connect() as db:
            db.execute(
                """
                CREATE TABLE IF NOT EXISTS sessions (
                    id INTEGER PRIMARY KEY AUTOINCREMENT,
                    sensor TEXT NOT NULL,
                    started_at TEXT NOT NULL,
                    stopped_at TEXT,
                    csv_path TEXT,
                    sample_count INTEGER DEFAULT 0,
                    stats_json TEXT DEFAULT '{}'
                )
                """
            )
            db.execute(
                """
                CREATE TABLE IF NOT EXISTS radar_samples (
                    session_id INTEGER NOT NULL,
                    timestamp_ms REAL NOT NULL,
                    raw_adc REAL NOT NULL,
                    voltage_mv REAL NOT NULL,
                    FOREIGN KEY(session_id) REFERENCES sessions(id)
                )
                """
            )
            db.execute(
                """
                CREATE TABLE IF NOT EXISTS imu_samples (
                    session_id INTEGER NOT NULL,
                    time_ms REAL NOT NULL,
                    ax REAL NOT NULL,
                    ay REAL NOT NULL,
                    az REAL NOT NULL,
                    gx REAL NOT NULL,
                    gy REAL NOT NULL,
                    gz REAL NOT NULL,
                    FOREIGN KEY(session_id) REFERENCES sessions(id)
                )
                """
            )
            db.execute(
                """
                CREATE TABLE IF NOT EXISTS a121_samples (
                    session_id INTEGER NOT NULL,
                    timestamp_ms REAL NOT NULL,
                    frame INTEGER NOT NULL,
                    peak_distance_m REAL NOT NULL,
                    peak_amplitude REAL NOT NULL,
                    peak_phase_rad REAL NOT NULL,
                    mean_amplitude REAL NOT NULL,
                    distances_m TEXT NOT NULL,
                    amplitude TEXT NOT NULL,
                    phase TEXT NOT NULL,
                    real TEXT NOT NULL,
                    imag TEXT NOT NULL,
                    acconeer_app_state TEXT,
                    acconeer_presence_detected INTEGER,
                    acconeer_presence_distance_m REAL,
                    acconeer_target_distance_m REAL,
                    acconeer_range_start_index INTEGER,
                    acconeer_range_end_index INTEGER,
                    acconeer_range_start_m REAL,
                    acconeer_range_end_m REAL,
                    acconeer_breathing_rate_bpm REAL,
                    FOREIGN KEY(session_id) REFERENCES sessions(id)
                )
                """
            )
            existing_a121_cols = {row[1] for row in db.execute("PRAGMA table_info(a121_samples)").fetchall()}
            for column_name, column_type in {
                "acconeer_app_state": "TEXT",
                "acconeer_presence_detected": "INTEGER",
                "acconeer_presence_distance_m": "REAL",
                "acconeer_target_distance_m": "REAL",
                "acconeer_range_start_index": "INTEGER",
                "acconeer_range_end_index": "INTEGER",
                "acconeer_range_start_m": "REAL",
                "acconeer_range_end_m": "REAL",
                "acconeer_breathing_rate_bpm": "REAL",
            }.items():
                if column_name not in existing_a121_cols:
                    db.execute(f"ALTER TABLE a121_samples ADD COLUMN {column_name} {column_type}")
            db.execute("CREATE INDEX IF NOT EXISTS idx_radar_session ON radar_samples(session_id)")
            db.execute("CREATE INDEX IF NOT EXISTS idx_imu_session ON imu_samples(session_id)")
            db.execute("CREATE INDEX IF NOT EXISTS idx_a121_session ON a121_samples(session_id)")

    def create_session(self, sensor: str, csv_path: Path | None) -> int:
        with self._connect() as db:
            cur = db.execute(
                "INSERT INTO sessions(sensor, started_at, csv_path) VALUES (?, ?, ?)",
                (sensor, datetime.now().isoformat(timespec="seconds"), str(csv_path) if csv_path else None),
            )
            return int(cur.lastrowid)

    def append_samples(self, sensor: str, session_id: int, rows: list[list[Any]]) -> None:
        if not rows:
            return
        with self._connect() as db:
            if sensor == "radar":
                db.executemany(
                    "INSERT INTO radar_samples(session_id, timestamp_ms, raw_adc, voltage_mv) VALUES (?, ?, ?, ?)",
                    [(session_id, row[0], row[1], row[2]) for row in rows],
                )
            elif sensor == "a121":
                normalized_rows = [
                    (list(row) + [None] * max(0, len(A121_CAPTURE_COLUMNS) - len(row)))[: len(A121_CAPTURE_COLUMNS)]
                    for row in rows
                ]
                db.executemany(
                    """
                    INSERT INTO a121_samples(
                        session_id, timestamp_ms, frame, peak_distance_m, peak_amplitude,
                        peak_phase_rad, mean_amplitude, distances_m, amplitude, phase, real, imag,
                        acconeer_app_state, acconeer_presence_detected,
                        acconeer_presence_distance_m, acconeer_target_distance_m,
                        acconeer_range_start_index, acconeer_range_end_index,
                        acconeer_range_start_m, acconeer_range_end_m,
                        acconeer_breathing_rate_bpm
                    ) VALUES (?, ?, ?, ?, ?, ?, ?, ?, ?, ?, ?, ?, ?, ?, ?, ?, ?, ?, ?, ?, ?)
                    """,
                    [(session_id, *row) for row in normalized_rows],
                )
            else:
                db.executemany(
                    """
                    INSERT INTO imu_samples(session_id, time_ms, ax, ay, az, gx, gy, gz)
                    VALUES (?, ?, ?, ?, ?, ?, ?, ?)
                    """,
                    [(session_id, *row) for row in rows],
                )

    def finish_session(self, session_id: int, sample_count: int, stats: dict[str, float | str]) -> None:
        with self._connect() as db:
            db.execute(
                "UPDATE sessions SET stopped_at = ?, sample_count = ?, stats_json = ? WHERE id = ?",
                (datetime.now().isoformat(timespec="seconds"), sample_count, json.dumps(stats), session_id),
            )

    def list_sessions(self) -> list[dict[str, Any]]:
        with self._connect() as db:
            db.row_factory = sqlite3.Row
            rows = db.execute(
                "SELECT id, sensor, started_at, stopped_at, csv_path, sample_count, stats_json "
                "FROM sessions ORDER BY id DESC LIMIT 500"
            ).fetchall()
        return [dict(row) for row in rows]

    def load_session(self, session_id: int, sensor: str) -> pd.DataFrame:
        with self._connect() as db:
            if sensor == "radar":
                return pd.read_sql_query(
                    "SELECT timestamp_ms AS Timestamp_ms, raw_adc AS RawADC, voltage_mv AS Voltage_mV "
                    "FROM radar_samples WHERE session_id = ? ORDER BY rowid",
                    db,
                    params=(session_id,),
                )
            if sensor == "a121":
                return pd.read_sql_query(
                    """
                    SELECT timestamp_ms AS Timestamp_ms, frame AS Frame,
                           peak_distance_m AS PeakDistance_m, peak_amplitude AS PeakAmplitude,
                           peak_phase_rad AS PeakPhase_rad, mean_amplitude AS MeanAmplitude,
                           distances_m AS Distances_m, amplitude AS Amplitude,
                           phase AS Phase, real AS Real, imag AS Imag,
                           acconeer_app_state AS AcconeerAppState,
                           acconeer_presence_detected AS AcconeerPresenceDetected,
                           acconeer_presence_distance_m AS AcconeerPresenceDistance_m,
                           acconeer_target_distance_m AS AcconeerTargetDistance_m,
                           acconeer_range_start_index AS AcconeerRangeStartIndex,
                           acconeer_range_end_index AS AcconeerRangeEndIndex,
                           acconeer_range_start_m AS AcconeerRangeStart_m,
                           acconeer_range_end_m AS AcconeerRangeEnd_m,
                           acconeer_breathing_rate_bpm AS AcconeerBreathingRate_BPM
                    FROM a121_samples WHERE session_id = ? ORDER BY rowid
                    """,
                    db,
                    params=(session_id,),
                )
            return pd.read_sql_query(
                "SELECT time_ms AS Time_ms, ax, ay, az, gx, gy, gz FROM imu_samples "
                "WHERE session_id = ? ORDER BY rowid",
                db,
                params=(session_id,),
            )


def _sample_rate(times_ms: np.ndarray, default: float) -> float:
    if len(times_ms) < 2:
        return default
    diffs = np.diff(times_ms) / 1000.0
    diffs = diffs[diffs > 0]
    return float(1.0 / np.mean(diffs)) if len(diffs) else default


def _radar_stats(df: pd.DataFrame) -> dict[str, float]:
    if df.empty:
        return {"sample_rate_hz": 0.0, "peak_hz": 0.0, "resp_bpm": 0.0, "speed_mps": 0.0}
    fs = _sample_rate(df["Timestamp_ms"].to_numpy(dtype=float), 500.0)
    voltage = df["Voltage_mV"].to_numpy(dtype=float)
    peak_hz = 0.0
    resp_bpm = 0.0
    if len(voltage) > 32:
        window = voltage[-4096:] if len(voltage) > 4096 else voltage
        window = (window - np.mean(window)) * np.hanning(len(window))
        spectrum = np.abs(np.fft.rfft(window))
        freqs = np.fft.rfftfreq(len(window), d=1.0 / max(fs, 1e-9))
        valid = freqs >= 0.05
        if np.any(valid):
            idx = int(np.argmax(spectrum[valid]))
            peak_hz = float(freqs[valid][idx])
        resp_valid = (freqs >= 0.1) & (freqs <= 0.6)
        if np.any(resp_valid):
            idx = int(np.argmax(spectrum[resp_valid]))
            resp_bpm = float(freqs[resp_valid][idx] * 60.0)
    return {"sample_rate_hz": fs, "peak_hz": peak_hz, "resp_bpm": resp_bpm, "speed_mps": peak_hz / DOPPLER_HZ_PER_MPS}


def _a121_stats(df: pd.DataFrame) -> dict[str, float]:
    analysis = analyze_a121_vitals(df, max_frames=1200)
    return {
        "sample_rate_hz": analysis.sample_rate_hz,
        "peak_distance_m": analysis.peak_distance_m,
        "peak_amplitude": analysis.peak_amplitude,
        "mean_amplitude": analysis.mean_amplitude,
        "target_distance_m": analysis.target_distance_m,
        "gate_min_m": analysis.gate_min_m,
        "gate_max_m": analysis.gate_max_m,
        "presence_score": analysis.presence_score,
        "present": 1.0 if analysis.present else 0.0,
        "resp_bpm": analysis.resp_bpm,
        "heart_bpm": analysis.heart_bpm,
    }


def _imu_stats(df: pd.DataFrame) -> dict[str, float]:
    if df.empty:
        return {"sample_rate_hz": 0.0, "accel_rms_g": 0.0, "gyro_rms_dps": 0.0, "resp_bpm": 0.0, "heart_bpm": 0.0}
    fs = _sample_rate(df["Time_ms"].to_numpy(dtype=float), 100.0)
    accel = df[["ax", "ay", "az"]].to_numpy(dtype=float)
    gyro = df[["gx", "gy", "gz"]].to_numpy(dtype=float)
    accel_mag = np.linalg.norm(accel, axis=1)
    gyro_mag = np.linalg.norm(gyro, axis=1)
    resp_bpm = 0.0
    heart_bpm = 0.0
    if len(accel_mag) > 32:
        signal = (accel_mag - np.mean(accel_mag)) * np.hanning(len(accel_mag))
        spectrum = np.abs(np.fft.rfft(signal))
        freqs = np.fft.rfftfreq(len(signal), d=1.0 / max(fs, 1e-9))
        resp_valid = (freqs >= 0.1) & (freqs <= 0.6)
        heart_valid = (freqs >= 0.65) & (freqs <= 4.0)
        if np.any(resp_valid):
            resp_bpm = float(freqs[resp_valid][int(np.argmax(spectrum[resp_valid]))] * 60.0)
        if np.any(heart_valid):
            heart_bpm = float(freqs[heart_valid][int(np.argmax(spectrum[heart_valid]))] * 60.0)
    return {
        "sample_rate_hz": fs,
        "accel_rms_g": float(np.sqrt(np.mean(np.square(accel_mag)))) if len(accel_mag) else 0.0,
        "gyro_rms_dps": float(np.sqrt(np.mean(np.square(gyro_mag)))) if len(gyro_mag) else 0.0,
        "resp_bpm": resp_bpm,
        "heart_bpm": heart_bpm,
    }


def _detect_sensor(df: pd.DataFrame) -> str:
    if all(col in df.columns for col in RADAR_COLUMNS):
        return "radar"
    if all(col in df.columns for col in A121_COLUMNS):
        return "a121"
    if all(col in df.columns for col in IMU_COLUMNS):
        return "imu"
    raise ValueError("CSV does not contain recognized HB100 radar, A121 radar, or IMU columns.")


class HzBpmAxisItem(pg.AxisItem):
    """Bottom axis that shows frequency in Hz with BPM equivalent on each tick."""

    def __init__(self, *args: Any, **kwargs: Any) -> None:
        super().__init__(*args, **kwargs)
        self.enableAutoSIPrefix(False)

    def tickStrings(self, values: list[float], scale: float, spacing: float) -> list[str]:
        strings: list[str] = []
        for v in values:
            hz = float(v) * scale
            bpm = hz * 60.0
            if abs(hz) < 1e-9:
                strings.append("0")
            else:
                strings.append(f"{hz:.2f}\n{bpm:.0f} BPM")
        return strings


class A121AnalysisThread(QtCore.QThread):
    analysis_completed = QtCore.Signal(int, object)

    def __init__(
        self,
        request_id: int,
        rows: list[list[Any]],
        cutoff_ms: float,
        gate_half_width: float,
        target_distance_m: float | None,
        heart_prior_hz: float | None,
        heart_prior_std_hz: float | None,
        use_gating: bool,
        auto_gate: bool,
        heart_window_s: float | None,
    ) -> None:
        super().__init__()
        self.request_id = request_id
        self.rows = rows
        self.cutoff_ms = cutoff_ms
        self.gate_half_width = gate_half_width
        self.target_distance_m = target_distance_m
        self.heart_prior_hz = heart_prior_hz
        self.heart_prior_std_hz = heart_prior_std_hz
        self.use_gating = use_gating
        self.auto_gate = auto_gate
        self.heart_window_s = heart_window_s

    def run(self) -> None:
        try:
            analysis_rows = [row for row in self.rows if float(row[0]) >= self.cutoff_ms]
            if not analysis_rows and self.rows:
                analysis_rows = [self.rows[-1]]
            columns = A121_CAPTURE_COLUMNS if analysis_rows and len(analysis_rows[0]) >= len(A121_CAPTURE_COLUMNS) else A121_COLUMNS
            df = pd.DataFrame(analysis_rows, columns=columns)
            analysis = analyze_a121_vitals(
                df,
                auto_gate=self.auto_gate,
                gate_half_width_m=self.gate_half_width,
                max_frames=len(df),
                target_distance_m=self.target_distance_m,
                heart_prior_hz=self.heart_prior_hz,
                heart_prior_std_hz=self.heart_prior_std_hz,
                use_gating=self.use_gating,
                heart_window_s=self.heart_window_s,
            )
            self.analysis_completed.emit(self.request_id, analysis)
        except Exception as exc:
            print(f"A121 analysis failed: {exc}", file=sys.stderr)


class A121SignalTestWindow(QtWidgets.QWidget):
    """Small utility window for comparing A121 peak signal strength setups."""

    def __init__(self, parent: QtWidgets.QWidget | None = None) -> None:
        super().__init__(parent)
        self.setWindowFlag(QtCore.Qt.WindowType.Window, True)
        self.setWindowTitle("A121 max amplitude / distance test")
        self.resize(420, 260)
        self.active = False
        self.start_ms: float | None = None
        self.samples: list[tuple[float, float]] = []

        layout = QtWidgets.QVBoxLayout(self)
        self.current_label = QtWidgets.QLabel("Current peak: waiting for A121 samples…")
        self.current_label.setStyleSheet("font-size: 16px; font-weight: 600;")
        layout.addWidget(self.current_label)

        row = QtWidgets.QHBoxLayout()
        row.addWidget(QtWidgets.QLabel("Test duration"))
        self.duration_spin = QtWidgets.QDoubleSpinBox()
        self.duration_spin.setRange(1.0, 120.0)
        self.duration_spin.setDecimals(1)
        self.duration_spin.setValue(10.0)
        self.duration_spin.setSuffix(" s")
        row.addWidget(self.duration_spin, 1)
        self.start_btn = QtWidgets.QPushButton("Start test")
        self.start_btn.clicked.connect(self.start_test)
        row.addWidget(self.start_btn)
        layout.addLayout(row)

        self.progress = QtWidgets.QProgressBar()
        self.progress.setRange(0, 100)
        self.progress.setValue(0)
        layout.addWidget(self.progress)

        self.result_label = QtWidgets.QLabel("Run a test to average the max amplitude and its distance.")
        self.result_label.setWordWrap(True)
        layout.addWidget(self.result_label)
        layout.addStretch(1)

    def start_test(self) -> None:
        self.active = True
        self.start_ms = None
        self.samples = []
        self.progress.setValue(0)
        self.result_label.setText(f"Collecting for {self.duration_spin.value():.1f} s…")

    def update_sample(self, timestamp_ms: float, peak_distance_m: float, peak_amplitude: float) -> None:
        if not (np.isfinite(timestamp_ms) and np.isfinite(peak_distance_m) and np.isfinite(peak_amplitude)):
            return
        self.current_label.setText(f"Current peak: amp {peak_amplitude:.1f} at {peak_distance_m:.3f} m")
        if not self.active:
            return
        if self.start_ms is None:
            self.start_ms = float(timestamp_ms)
        elapsed_s = max(0.0, (float(timestamp_ms) - self.start_ms) / 1000.0)
        duration_s = float(self.duration_spin.value())
        self.samples.append((float(peak_amplitude), float(peak_distance_m)))
        self.progress.setValue(int(np.clip(100.0 * elapsed_s / max(duration_s, 1e-9), 0.0, 100.0)))
        if elapsed_s >= duration_s:
            self.finish_test()

    def finish_test(self) -> None:
        self.active = False
        self.progress.setValue(100)
        if not self.samples:
            self.result_label.setText("No valid A121 peak samples were collected.")
            return
        samples = np.asarray(self.samples, dtype=float)
        amp = samples[:, 0]
        dist = samples[:, 1]
        self.result_label.setText(
            f"Result over {len(samples)} frames:\n"
            f"Avg max amplitude: {float(np.mean(amp)):.1f}  (std {float(np.std(amp)):.1f})\n"
            f"Avg distance of max amplitude: {float(np.mean(dist)):.3f} m  (std {float(np.std(dist)):.3f} m)"
        )
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

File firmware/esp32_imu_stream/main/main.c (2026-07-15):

#include "driver/i2c.h"
#include "esp_err.h"
#include "esp_log.h"
#include "esp_timer.h"
#include "freertos/FreeRTOS.h"
#include "freertos/task.h"
#include <inttypes.h>
#include <stdint.h>
#include <stdio.h>

#define I2C_MASTER_SCL_IO 22      /*!< GPIO number used for I2C master clock */
#define I2C_MASTER_SDA_IO 21      /*!< GPIO number used for I2C master data  */
#define I2C_MASTER_NUM 0          /*!< I2C port number for master dev */
#define I2C_MASTER_FREQ_HZ 400000 /*!< I2C master clock frequency */
#define I2C_MASTER_TX_BUF_DISABLE 0 /*!< I2C master doesn't need buffer */
#define I2C_MASTER_RX_BUF_DISABLE 0 /*!< I2C master doesn't need buffer */
#define I2C_MASTER_TIMEOUT_MS 100

#define LSM6DS3_ADDR 0x6B /*!< Sensor address */
#define LSM6DS3_WHO_AM_I_REG 0x0F
#define LSM6DS3_CTRL1_XL 0x10
#define LSM6DS3_CTRL2_G  0x11
#define LSM6DS3_CTRL3_C  0x12
#define LSM6DS3_STATUS_REG 0x1E
#define LSM6DS3_OUTX_L_G 0x22

#define LSM6DS3_ODR_104_HZ 0x40
#define LSM6DS3_BDU_IF_INC 0x44

static const char *TAG = "IMU_STREAM";

/**
 * @brief i2c master initialization
 */
static esp_err_t i2c_master_init(void) {
  int i2c_master_port = I2C_MASTER_NUM;

  i2c_config_t conf = {
      .mode = I2C_MODE_MASTER,
      .sda_io_num = I2C_MASTER_SDA_IO,
      .scl_io_num = I2C_MASTER_SCL_IO,
      .sda_pullup_en = GPIO_PULLUP_ENABLE,
      .scl_pullup_en = GPIO_PULLUP_ENABLE,
      .master.clk_speed = I2C_MASTER_FREQ_HZ,
  };

  i2c_param_config(i2c_master_port, &conf);

  return i2c_driver_install(i2c_master_port, conf.mode,
                            I2C_MASTER_RX_BUF_DISABLE,
                            I2C_MASTER_TX_BUF_DISABLE, 0);
}

static esp_err_t lsm6ds3_register_read(uint8_t reg_addr, uint8_t *data,
                                       size_t len) {
  return i2c_master_write_read_device(
      I2C_MASTER_NUM, LSM6DS3_ADDR, &reg_addr, 1, data, len,
      I2C_MASTER_TIMEOUT_MS / portTICK_PERIOD_MS);
}

static esp_err_t lsm6ds3_register_write_byte(uint8_t reg_addr, uint8_t data) {
  uint8_t write_buf[2] = {reg_addr, data};
  return i2c_master_write_to_device(I2C_MASTER_NUM, LSM6DS3_ADDR, write_buf,
                                    sizeof(write_buf),
                                    I2C_MASTER_TIMEOUT_MS / portTICK_PERIOD_MS);
}

void app_main(void) {
  ESP_ERROR_CHECK(i2c_master_init());
  ESP_LOGI(TAG, "I2C initialized successfully");

  uint8_t who_am_i;
  ESP_ERROR_CHECK(lsm6ds3_register_read(LSM6DS3_WHO_AM_I_REG, &who_am_i, 1));
  ESP_LOGI(TAG, "WHO_AM_I: 0x%02X", who_am_i);

  // CTRL1_XL: 104 Hz ODR, +/-2 g. CTRL2_G: 104 Hz ODR, +/-245 dps.
  ESP_ERROR_CHECK(
      lsm6ds3_register_write_byte(LSM6DS3_CTRL1_XL, LSM6DS3_ODR_104_HZ));
  ESP_ERROR_CHECK(
      lsm6ds3_register_write_byte(LSM6DS3_CTRL2_G, LSM6DS3_ODR_104_HZ));
  // Block Data Update keeps a complete sample stable during the 12-byte read;
  // IF_INC enables sequential register addressing.
  ESP_ERROR_CHECK(
      lsm6ds3_register_write_byte(LSM6DS3_CTRL3_C, LSM6DS3_BDU_IF_INC));
  ESP_LOGI(TAG, "LSM6DS3 configured for 104 Hz");

  uint8_t data[12];
  int16_t ax, ay, az, gx, gy, gz;
  uint32_t sample_index = 0;

  ESP_LOGI(TAG, "Starting 6-axis stream...");

  while (1) {
    uint8_t status;
    if (lsm6ds3_register_read(LSM6DS3_STATUS_REG, &status, 1) != ESP_OK) {
      vTaskDelay(pdMS_TO_TICKS(1));
      continue;
    }

    if ((status & 0x03) == 0x03) { // Both XL and G data ready
      if (lsm6ds3_register_read(LSM6DS3_OUTX_L_G, data, sizeof(data)) ==
          ESP_OK) {
        const int64_t device_time_us = esp_timer_get_time();

        gx = (int16_t)((data[1] << 8) | data[0]);
        gy = (int16_t)((data[3] << 8) | data[2]);
        gz = (int16_t)((data[5] << 8) | data[4]);
        ax = (int16_t)((data[7] << 8) | data[6]);
        ay = (int16_t)((data[9] << 8) | data[8]);
        az = (int16_t)((data[11] << 8) | data[10]);

        // Print: sample_index,device_time_us,ax,ay,az,gx,gy,gz
        // XL scale: 2G (0.061 mg/LSB)
        // G scale: 245 dps (8.75 mdps/LSB)
        printf("%" PRIu32 ",%" PRId64 ",%.4f,%.4f,%.4f,%.3f,%.3f,%.3f\n",
               sample_index, device_time_us,
               (float)ax * 0.061 / 1000.0,
               (float)ay * 0.061 / 1000.0,
               (float)az * 0.061 / 1000.0,
               (float)gx * 8.75 / 1000.0,
               (float)gy * 8.75 / 1000.0,
               (float)gz * 8.75 / 1000.0);
        sample_index++;
      }
    }
    vTaskDelay(pdMS_TO_TICKS(1));
  }
}

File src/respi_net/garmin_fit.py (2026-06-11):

"""Small Garmin FIT reader for wellness/sleep reference exports.

This is intentionally dependency-free.  It implements the FIT record/definition layer and extracts
only the wellness data needed by the A121 sleep comparison tooling:

- monitoring heart-rate samples (global 55, timestamp_16 + heart_rate)
- respiration-rate samples (global 297)
- sleep level changes (global 275)
- sleep start/stop events (global 21, event 74 in Garmin sleep exports)
"""

from __future__ import annotations

from dataclasses import dataclass
from datetime import datetime, timedelta, timezone
from pathlib import Path
import struct
from typing import Any, Iterable

import pandas as pd

FIT_EPOCH = datetime(1989, 12, 31, tzinfo=timezone.utc)

# name, byte-size, struct format, invalid value
_BASE_TYPES: dict[int, tuple[str, int, str, int | None]] = {
    0x00: ("enum", 1, "B", 0xFF),
    0x01: ("sint8", 1, "b", 0x7F),
    0x02: ("uint8", 1, "B", 0xFF),
    0x83: ("sint16", 2, "h", 0x7FFF),
    0x84: ("uint16", 2, "H", 0xFFFF),
    0x85: ("sint32", 4, "i", 0x7FFFFFFF),
    0x86: ("uint32", 4, "I", 0xFFFFFFFF),
    0x07: ("string", 1, "s", 0x00),
    0x88: ("float32", 4, "f", 0xFFFFFFFF),
    0x89: ("float64", 8, "d", 0xFFFFFFFFFFFFFFFF),
    0x0A: ("uint8z", 1, "B", 0x00),
    0x8B: ("uint16z", 2, "H", 0x0000),
    0x8C: ("uint32z", 4, "I", 0x00000000),
    0x0D: ("byte", 1, "B", None),
    0x8E: ("sint64", 8, "q", 0x7FFFFFFFFFFFFFFF),
    0x8F: ("uint64", 8, "Q", 0xFFFFFFFFFFFFFFFF),
    0x90: ("uint64z", 8, "Q", 0x0000000000000000),
}


@dataclass(frozen=True)
class FitMessage:
    global_num: int
    fields: dict[int, Any]
    path: Path


@dataclass(frozen=True)
class _FieldDef:
    number: int
    size: int
    base_type: int


@dataclass(frozen=True)
class _DevFieldDef:
    number: int
    size: int
    developer_index: int


@dataclass(frozen=True)
class _Definition:
    endian: str
    global_num: int
    fields: tuple[_FieldDef, ...]
    developer_fields: tuple[_DevFieldDef, ...]


@dataclass(frozen=True)
class GarminReferenceData:
    heart_rate: pd.DataFrame
    respiration_rate: pd.DataFrame
    sleep_levels: pd.DataFrame
    sleep_events: pd.DataFrame


def fit_datetime(timestamp_s: int | float) -> datetime:
    """Convert a FIT date_time value to a timezone-aware UTC datetime."""

    return FIT_EPOCH + timedelta(seconds=float(timestamp_s))


def fit_datetime_local_naive(timestamp_s: int | float) -> datetime:
    """Convert FIT date_time seconds to the machine-local naive datetime used by plots."""

    return fit_datetime(timestamp_s).astimezone().replace(tzinfo=None)


def _base_info(base_type: int) -> tuple[str, int, str, int | None]:
    # Base types are normally exact values above.  The fallback keeps the parser tolerant of files
    # that set non-profile flag bits while preserving the low base-type id.
    return _BASE_TYPES.get(base_type) or _BASE_TYPES.get(base_type & 0xDF) or ("byte", 1, "B", None)


def _read_value(data: bytes, offset: int, size: int, base_type: int, endian: str) -> Any:
    name, unit_size, fmt, invalid = _base_info(base_type)
    raw = data[offset : offset + size]
    if name == "string":
        return raw.split(b"\x00", 1)[0].decode("utf-8", "replace")
    if name == "byte":
        values = list(raw)
        return values[0] if len(values) == 1 else values
    if unit_size <= 0 or size % unit_size != 0:
        return raw.hex()
    count = size // unit_size
    if unit_size == 1:
        values = list(raw)
        if fmt == "b":
            values = [struct.unpack("b", bytes([value]))[0] for value in values]
    else:
        values = list(struct.unpack(endian + (fmt * count), raw))
    cleaned: list[Any] = [None if invalid is not None and value == invalid else value for value in values]
    return cleaned[0] if count == 1 else cleaned


def parse_fit_file(path: Path) -> list[FitMessage]:
    """Parse a FIT file into generic messages keyed by global message and field numbers."""

    path = Path(path)
    data = path.read_bytes()
    if len(data) < 12:
        raise ValueError(f"{path} is too small to be a FIT file")
    header_size = data[0]
    if header_size < 12 or len(data) < header_size:
        raise ValueError(f"{path} has an invalid FIT header")
    data_size = struct.unpack_from("<I", data, 4)[0]
    if data[8:12] != b".FIT":
        raise ValueError(f"{path} does not contain FIT magic bytes")

    offset = header_size
    data_end = min(len(data), header_size + data_size)
    definitions: dict[int, _Definition] = {}
    messages: list[FitMessage] = []
    last_timestamp: int | None = None

    while offset < data_end:
        header = data[offset]
        offset += 1
        compressed_timestamp: int | None = None

        if header & 0x80:
            is_definition = False
            has_developer_fields = False
            local_num = (header >> 5) & 0x03
            time_offset = header & 0x1F
            if last_timestamp is not None:
                compressed_timestamp = (last_timestamp & ~0x1F) + time_offset
                if compressed_timestamp <= last_timestamp:
                    compressed_timestamp += 32
        else:
            is_definition = bool(header & 0x40)
            has_developer_fields = bool(header & 0x20)
            local_num = header & 0x0F

        if is_definition:
            if offset + 5 > data_end:
                raise ValueError(f"Truncated FIT definition in {path}")
            # reserved byte, architecture byte
            architecture = data[offset + 1]
            offset += 2
            endian = ">" if architecture else "<"
            global_num = struct.unpack_from(endian + "H", data, offset)[0]
            offset += 2
            field_count = data[offset]
            offset += 1
            fields: list[_FieldDef] = []
            for _ in range(field_count):
                if offset + 3 > data_end:
                    raise ValueError(f"Truncated FIT field definition in {path}")
                fields.append(_FieldDef(data[offset], data[offset + 1], data[offset + 2]))
                offset += 3
            developer_fields: list[_DevFieldDef] = []
            if has_developer_fields:
                developer_count = data[offset]
                offset += 1
                for _ in range(developer_count):
                    if offset + 3 > data_end:
                        raise ValueError(f"Truncated FIT developer field definition in {path}")
                    developer_fields.append(_DevFieldDef(data[offset], data[offset + 1], data[offset + 2]))
                    offset += 3
            definitions[local_num] = _Definition(endian, global_num, tuple(fields), tuple(developer_fields))
            continue
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

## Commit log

2026-05-31 schematics, a121 support , wip a121 app
    [esp32_imu_schematic.kicad_sch, schematics.kicad_pcb, schematics.kicad_sch]
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2026-07-14 Expand thesis methodology and measurement plan
    Add the radar and IMU background, one-day validation protocol, foil-angle retest, apparatus photographs, and compiled thesis. Replace the saved Acconeer page with the official URL and keep local measurement sessions out of Git.
2026-07-14 Harden sensor capture workflows
    Add BLE discovery and probe diagnostics for the iPhone IMU, synchronize serial capture buffers, close reader threads safely, and make sampling-rate estimation robust to timing outliers. Cover the new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
2026-07-15 Stabilize HB100 capture and refine thesis measurements
    [app.py, cli.py, radar.py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]
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2026-09-11 fix(a121): take heart rate from cardiac motion, not breathing harmonics
    The heart estimate averaged the few bins around the target and softly
    subtracted breathing, so a stronger breathing harmonic in the heart band often
    won, and heart motion a few cm from the chest return was missed.
    The heart search now looks at every range bin within 12 cm of the target. Each
    bin's heart-band power is weighted down where it is coherent with harmonic
    templates that follow the breathing phase, and peaks locked to breathing are
    never used. Spectra are averaged with neighbouring bins, and a peak has to
    stand out clearly, otherwise the heart rate stays 0. heart_signal gets the same
    weighting, so the plot show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
    [a121_vitals.py]
2026-09-27 feat: standardize breathing patterns and add a coach timeline
    Breathing protocols are now JSON pattern files in configs/breathing_patterns
    (single phases, paced cycles with optional in-cycle holds, repeats), loaded
    and strictly validated by respi_net.breathing.
    Every guided-breathing screen uses one coach panel: a colour-coded timeline
    of the whole session with named sections and a cursor, the current cue with
    a draining bar and seconds left, and the next cue, highlighted in the last
    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
2026-09-27 feat(nn): adopt breathing-phase classes and per-breath cue alignment
    - Phase classes follow Szymanski et al. (Sci Data 2025): 0 inhale,
    1 hold after exhale, 2 exhale, 3 hold after inhale, 999 noise
    (class 4 in arrays), -1 = no label.
    - Chest-signal front end for phases: low-pass only (2 Hz) plus one
    straight-line detrend, velocity and echo strength; the 0.1-0.5 Hz rate
    band-pass is kept only for comparisons because it moves holds to the
    mid-breath level and adds fake motion at their edges.
    - Cue alignment: global lag matched on velocity, every boundary snapped
    to where the motion turns, stops or starts, fallback to the lag-shifted
    cue with a wider mask, and IGNORE around each b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
    [breath_phases.py, chest_signal.py, label_alignment.py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]
2026-09-27 feat(nn): correct coach labels, add phase baseline and dataset export
    - tools/build_breath_phase_labels.py turns all 19 A121 coach recordings
    into per-breath corrected labels, per-run charts (PNG + one PDF),
    baseline scores and a 30 s window dataset split by run, all under the
    git-ignored data/processed/breath_phases/.
    - Deterministic phase detector (offline and real time) with settings
    tuned on the coach runs: 93.0% / 84.7% accuracy, hold F1 0.91 / 0.80.
    - nn_dataset: labelled runs in physical units, per-window normalisation
    (depth-independent), group-wise splits and one npz format.
    - Thesis figures: corrected labels over the A121 signal, and a breath
    hold through the 0.1-0.5 Hz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
    [nn_dataset.py, phase_baseline.py]
2026-09-27 feat(nn): synthetic breathing data and iPhone labelling check
    - breath_synth: labelled synthetic breathing (rates 5-35/min, depths
    0.2-12 mm, holds after inhale and exhale, sighs, heartbeat, drift,
    NOISE-labelled motion bursts), an A121 forward/inverse model that
    reproduces phase wrapping and low-SNR unwrap failures, and label-safe
    augmentations (depth, time warp, recorded noise bank, drift, crops).
    - tools/validate_imu_phase_reference.py labels the iPhone and LSM6DS3
    chest recordings independently and compares them: as recorded the
    iPhone clock is seconds off; after one per-run clock offset (found by
    matching motion envelopes, then velocities) boundaries differ by
    0.3-0.4 s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
    [breath_synth.py, chest_signal.py, validate_imu_phase_reference.py]
2026-09-27 fix(nn): check iPhone and LSM6DS3 recordings separately
    The iPhone and LSM6DS3 files are separate recordings, so comparing and
    aligning them against each other was wrong, and so was the conclusion
    drawn from it that the iPhone clock is seconds off. Each recording is
    now labelled against its own cues and described by the same numbers as
    the radar coach runs (lag, cue match, boundaries without a clear turn,
    boundary shift spread, agreement of the cue-free detector). The
    cross-sensor offset estimation is removed and the figure replaced.
    [chest_signal.py, validate_imu_phase_reference.py]
2026-09-27 feat(nn): guided A121 + iPhone recorder and training patterns
    - tools/a121_iphone_guided_recording.py records the A121 and the iPhone
    IMU app together with the breathing coach, one pattern per trial:
    three CSVs per trial (A121, iPhone, cues with wall times) and an
    atomic manifest; incomplete iPhone streams, phone stream restarts and
    short A121 captures are rejected and their files removed; Esc
    discards. Per-packet BLE arrival statistics are kept per trial so the
    phone clock offset can be corrected later.
    - Five nn_* patterns for training data (~17 min per session): free
    breathing, rates 6-25/min with different inhale:exhale splits, holds
    after inhale and after exhale (3-15 s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
2026-09-27 feat(nn): phase model and trainer, AD8232 heart-rate prep, held-breath labels
    - phase_model: causal TCN (receptive field 25.45 s at 20 Hz, 44k
    parameters) and GRU taggers, a streaming detector that matches a
    full-sequence pass, an online anti-flicker smoother and checkpoints.
    - tools/train_breath_phase_model.py: masked cross-entropy with class
    weights, early stopping on validation macro-F1 after Viterbi decoding,
    --evaluate and --smoke; nothing has been trained on real data yet.
    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
2026-09-27 fix(nn): class codes follow the paper, 0 exhale and 2 inhale
    Szymański et al. number breath-out 0 and breath-in 2; inhale and exhale
    were the other way round. Hold, noise and ignore codes are unchanged.
    [breath_phases.py]
2026-09-27 feat(nn): loader and analysis for the Szymański respiratory-phase dataset
    Reads the belt and accelerometer recordings with their hand labels
    (file codes are the paper's minus one), pairs samples by time and turns
    them into labelled runs on the 20 Hz grid. The analysis scores the
    phase detector on every sensor and on the coach data, measures how late
    real-time decisions come, and exports the belt recordings as a
    pre-training dataset. Boundary metrics now report the median delay.
    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
2026-09-27 docs(thesis): external belt dataset, corrected class table, boundary delay
2026-09-27 fix(nn): undo the timing faults in the Szymański hand labels
    Their labelling tool shows a smoothed copy of the signal made with
    np.convolve(mode="valid") and stored against untrimmed time stamps, so
    it runs (w-1)/2 samples ahead of the raw signal: 0.2 s on the belt and on
    the iNode accelerometer. Its running 15 s min-max also pins record-deep
    breaths at +-1 while the chest still moves, so deep inhales were cut short
    by early holds. Labels are now delayed by the smoothing lead and a hold
    starts where the chest stops moving the breath's way; the quick settle
    after a deep inhale is left unlabelled. WitMotion labels, copied from the
    belt by time stamp and 0.2-0.8 s off per file, are left as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
    [szymanski_dataset.py]
2026-09-27 fix(nn): exact smoothing lead per session for the Szymański labels
    Their stored column is rebuilt sample for sample with a 5-sample average
    for the iNode-session belt, 6 for the WitMotion-session belt (5 for its
    yellow recording), 11 and 12 for the accelerometers. The labels are now
    moved back by (w-1)/2 samples on their own time stamps, which handles the
    half-sample lead of even widths.
    [szymanski_dataset.py]
2026-09-28 fix(nn): a settle into a hold is part of the hold
    After a deep inhale the chest often drops a little as the breath is
    held: with the glottis closed, volume shifts between chest and belly
    without air moving, so the lungs stay full. The corrected Szymański
    labels keep that settle in the hold (as their labellers had it) instead
    of leaving it unlabelled, and the detector treats a move back of up to
    0.8 s that stops within 40% of the breath's depth from where the breath
    ended as the start of the hold, named after that breath. The limits
    leave every coach recording unchanged, where holds interrupt an exhale
    halfway; on the belt real-time agreement rises from 57.1% to 58.9%.
    The analysis reports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
    [phase_baseline.py, szymanski_dataset.py]
2026-09-28 feat(nn): augmented and synthetic training data, label timing figure
    tools/build_artificial_data.py adds six copies of every training run,
    played at 0.7-1.4x speed with real A121 noise from the coached holds and
    a slow drift, plus 300 min of synthetic A121 runs, and exports two sets:
    dataset_pretrain_v1.npz (belt, copies, synthetic) and
    dataset_finetune_v1.npz (own A121 runs and copies). Validation and test
    stay real and copies never leave their original's split. The summary
    lists labelled minutes per source and class.
    The Szymański analysis also draws the raw belt against the smoothed copy
    the labels were drawn on, in Polish for the thesis and in English for
    notes, with no text inside t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
    [artificial_runs.py]
2026-09-28 docs(thesis): transfer-learning numbers checked, why the network is trained here
    Lu et al. report F1 0.61 radar-only vs 0.82 after PSG pre-training in
    their main comparison, but 0.77 for training from scratch in their
    ablation; the text now gives both. None of the related models can be
    trained further for this task (app-only files, no weights, or data on
    request only), so the network is trained here with pre-training on belt
    and synthetic data. The validation plan follows the recording plan.
2026-09-29 feat(ios): RespiPhoneIMU 1.1, made for a phone strapped to the body
    - checklist before a trial (Bluetooth, visible, Mac connected, battery,
    Low Power Mode) and a placement check: a live line of the chest's tilt
    with its size in mg;
    - a dark full-screen view while streaming with the elapsed time, Mac
    link state, live line and measured rate; the screen dims, and stopping
    from the phone takes a 2 s hold so a strap cannot stop a trial;
    - vibration and a red banner when the Mac drops out;
    - every trial also saved on the phone as a CSV in the desktop IMU
    columns (Unix ms), with share and delete, visible in the Files app.
    The BLE protocol is unchanged, so the desktop recorder needs no ch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
2026-09-30 fix(nn): remove the A121 driver's 0.17% clock drift from the radar time axis; 12 min phone+radar run in the thesis
    [a121.py, chest_signal.py]
2026-10-01 feat(nn): merged hold class and a fused cue+both-sensors reference for the phone labelling check; thesis rewritten around it
2026-10-01 feat(nn): undo shortcuts and right-click removal in the annotation viewer; hold rule 4 s from measured rests vs holds
    [phone_annotation.py]
2026-10-01 data(nn): first hand annotation of the phone trace (phase1_halfside_02, 60-160 s, pass 1)
    [phase1_halfside_02__run_01_nn_self_3min__maciek__60-160__pass1.csv]
2026-10-01 feat(nn): snap hand labels and detector to the trace's turning points; relabelled 60-160 s and 10-60 s
    [phase1_halfside_02__run_01_nn_self_3min__maciek__10-60__pass1.csv, phase1_halfside_02__run_01_nn_self_3min__maciek__60-160__pass1.csv, phase1_lying_01__run_01_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]
2026-10-01 data(nn): hand annotation of phase1_lying_01, 20-100 s
    [phase1_lying_01__run_01_nn_self_3min__maciek__20-100__pass1.csv]
2026-10-01 data(nn): hand annotation of self_lying_3min_01, 20-160 s
    [self_lying_3min_01__run_01_nn_self_3min__maciek__20-160__pass1.csv]
2026-10-01 feat(nn): slow-motion check for the phone detector, labeller convention measurement, hand-label results in the thesis
    [self_lying_3min_01__run_01_nn_self_3min__maciek__20-160__pass1.csv]
2026-10-01 feat(nn): detector defaults to a 4 s hold and the slow-motion check, belt labels folded to the 4 s rule, thesis tables regenerated; other people recordings to background
2026-10-02 data(nn): second labelling pass of phase1_lying_01, 100-180 s
    [phase1_lying_01__run_01_nn_self_3min__maciek__100-180__pass2.csv]
2026-10-02 feat(nn): second labelling pass of self_lying_3min_01; guard at both hold edges; reliability in the thesis
    [self_lying_3min_01__run_01_nn_self_3min__maciek__20-160__pass2.csv]
2026-10-02 data(nn): second labelling pass of phase1_halfside_02, 10-60 s; reliability of all three stretches in the thesis
    [phase1_halfside_02__run_01_nn_self_3min__maciek__10-60__pass2.csv]
2026-10-02 feat(nn): annotation viewer snaps to the turning point at click time with a preview, zoom and pan; offset handling documented
    [phone_annotation.py]
2026-10-03 docs(thesis): phone reference reopened: unguarded scores, accelerometer limitation, repeatability not accuracy; fix noise-bank leak in the artificial data
    [phone_annotation.py]
2026-10-03 feat(nn): phone orientation distance keeps the lung level through holds after deep inhales; figure against the single-axis trace
2026-10-04 docs(thesis): phone on the middle of the chest takes over the radar echo and is a poor tilt sensor; 1-minute pattern for the comparison
2026-10-04 docs(thesis): forward motion of the sternum is too small for the phone's accelerometer and shows no level in a hold
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2026-10-08 feat(app): show the phase-network chest signal live and in recordings
    The A121 view now plots chest motion in mm with only the 2 Hz low-pass, so holds stay
    flat (~0.1 s filter lag instead of ~1.2-1.5 s). Velocity, inhale/exhale shading and the
    band-pass breathing/heart view move to the View menu. Curated demo recordings list,
    --open to start on a recording, scrollable side panel without boxed labels.
2026-10-08 feat(app): show chest velocity by default as a small strip under the chest trace
2026-10-08 fix(app): open demo recordings from the Recordings tab and title them with their description
    [app.py]
2026-10-12 feat(belt): strain-belt capture, radar + belt guided sessions and belt phase labels
    - respi_net.strain_belt: BLE receiver for the ESP32/HX711 belt (text counts or JSON packets), CLI scan/probe/capture
    - guided recorder: --reference belt|both records A121 and the belt in one session, with a belt quality gate
    - chest_signal.strain_belt_chest_signal: cleaning, even 10 Hz grid, end-expiratory drift removal
    - tools/label_strain_belt_runs.py: phase labels from the belt alone, live detector and cue compliance scores
    - coach --belt, belt_holds_1m pattern, showcase launchers for an overnight radar run and a radar + belt session
2026-10-12 feat(annotation): hand-label the strain belt and score the belt labels against it
    - annotate_phone_phases.py --belt: belt trace on the belt labeller's time axis; holds from 2 s
    - clicks snap to the nearest real turn (trough -> inhale, crest -> exhale); a slope does not snap
    - a second click within 0.3 s replaces the mark instead of leaving a sliver of a phase
    - score_phone_annotations.py belt: agreement, snapped agreement and each side's turn offsets
    - first pass on 4 windows (2 recordings, 85 boundaries): 92.4% raw agreement, all boundaries found
2026-10-20 feat(phases): breaths start at the turn of the trace; drop the boundary-convention code
    - offline detector: an inhale starts at the trough, an exhale at the crest of the 1 Hz trace, within 0.8 s of the breath's onset (as the labelling viewer snaps)
    - old phone annotations snapped once with the viewer's rule; raw clicks kept in clicked_start_s
    - removed boundary_offsets, shift_boundaries, snap_segments, snap_labels and the convention/snapped scores
    - second blind pass over the four belt windows: passes agree 98.0-99.4%, belt labels vs hand 94.5-95.2% (was 92.4-93.0%)
    - thesis: tables and text recomputed for the new rule, effects per dataset, strain belt as a reference
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2026-10-21 feat(phases): fast breathing gets lighter detector settings
    - offline, a clear rhythm above 0.6 Hz (dominant over a 20 s window, at least 20 % of a typical breath) switches
    that stretch to lighter smoothing, a shorter slow-motion window, shorter phases and a shorter turn reach
    - synthetic breathing 40-120/min now 87-99 % (was 55-87 %, collapsing from about 55/min); below 0.6 Hz labels unchanged
    - the amplitude condition keeps the heartbeat in a hold from passing for fast breathing
    - every own dataset scores the same; Szymański belt +2.2, iNode +3.4 (hyperventilation); thesis updated
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2026-11-07 feat(hr): flag where the heart-rate strap can be trusted
    A loose or nearly flat strap sends spurious short beats and its reported rate drifts up with them
    (2026-11-07: 56 -> 85 /min while the radar stayed at ~55). heart_strap_quality checks every RR
    interval against the rate reported with it; within +-30 s more than 20% artefacts makes the RR
    intervals untrusted and more than 70% (or lost contact) the rate too. capture-heart-strap writes
    <name>_quality.csv beside each recording, heart-strap-quality flags older ones, and the summary
    gives the trusted shares. capture-strain-belt now ends with a dropout summary.
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2026-11-07 fix(hr): a strap locked onto spurious beats is not trusted
    On 2026-11-07 the strap reported 104-126 /min at rest (radar ~55) with RR intervals agreeing with that
    rate, so the artefact share stayed low and the rate was flagged as trusted. Beats at rest are regular:
    the median successive RR change over the median interval was 0.02-0.04 on clean minutes, 0.11-0.12 where
    the rate still matched the radar, and 0.19-0.59 on every bad minute. Above 0.06 the RR intervals and
    above 0.15 the rate are now untrusted; the flags carry rr_irregularity.
2026-11-07 feat(a121): the range selection leaves the old choice below 0.65 of the best group instead of half
    On the ~130 cm radar + belt recording the kept range breathed shallowly while bins 10-20 cm closer scored
    twice as high (3.5 against 7.0), just missing the half rule. Over 38 recordings with a reference
    (compare_a121_range_selection.py --keep-old-fraction), 0.65 changes 7 against 0.5: cues 90.9 -> 93.8%
    (3, worst -2.4 pt), phone 83.2 -> 91.3% (2), hand labels 79.6 -> 88.6% (2), belt 66.0 -> 78.8% (2);
    0.8 adds only even or unscored ones. Live (replay, new --keep-old-fraction) the belt agreement where the
    selection moved goes 74.6 -> 83.6% with none worse, at 47 switches over the 38 runs inste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
2026-11-08 feat(nn): narrower copies and a heavier hold class tried for the short holds of free breathing; neither helps
    train_breath_phase_model.py gains --class-scale CLASS=FACTOR (multiply one class weight after the
    inverse-frequency weighting). compare_breath_phase_training.py gains the variants narrow (copies
    0.8-1.25x), tight (0.9-1.1x) and hold2 (hold weight doubled), scores the coach and belt parts of the test
    split apart, and counts the distinct belt holds each model finds; --tag names the summary files.
    TCN, seeds 0-2, live, belt test: holds found of 6 -- real only 3/4/4, copies 1/2/1, pre-trained 2/2/6,
    narrow 2/2/4, tight 1/1/3, hold2 2/2/2, detector 5. Stretching does not destroy the ho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
2026-11-09 feat(sleep): every night in one compact file, 30 s epochs with breathing, heart and movement features, sleep stages from each against the watch, and a heart-rate network against the night pipeline
    Sleep stages (7 nights, leave-one-night-out): no radar feature set beats the time of night (kappa <= 0.07 vs 0.11);
    the watch's own heart rate differs by 3 bpm between its stages. Heart rate (5 watch nights): the time-domain network
    picked by validation has 3.6 bpm MAE at the pipeline's coverage (pipeline 3.85) and keeps that error on 81% of windows
    (pipeline 65%); over 10-minute medians the pipeline is closer (2.8 vs 3.3 bpm).
2026-11-09 feat(sleep): the watch's stress and HRV and the radar's beat-to-beat variability join the sleep epochs; even the watch's own exported signals explain its stages weakly (kappa <= 0.14), and strap labe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
    The 20:16 strap session fails the check and is dropped. Radar RMSSD tracks the watch's HRV only on the best night
    (r 0.50 on 10-minute medians) and does not help the stage models.
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2026-11-10 docs: Bidsleep in the stage pretraining does not bring the radar nights closer to Garmin; the zero-shot model gives a plausible night structure but too much deep sleep
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
